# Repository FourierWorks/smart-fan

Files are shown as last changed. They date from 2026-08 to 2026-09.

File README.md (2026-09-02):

# Smart Fan Retrofit - Philips 2000 Series (CX2550/00)

Retrofitting a Philips CX2550/00 pedestal fan for control via Home Assistant,
without modifying the fan's mains wiring. An ESP32 running ESPHome electronically
"presses" the fan's existing buttons through optocouplers, and Home Assistant
provides the control dashboard over the native ESPHome API.

The fan's physical buttons remain fully functional - the retrofit is entirely
additive and reversible.

## Photos

**Interface board - front**

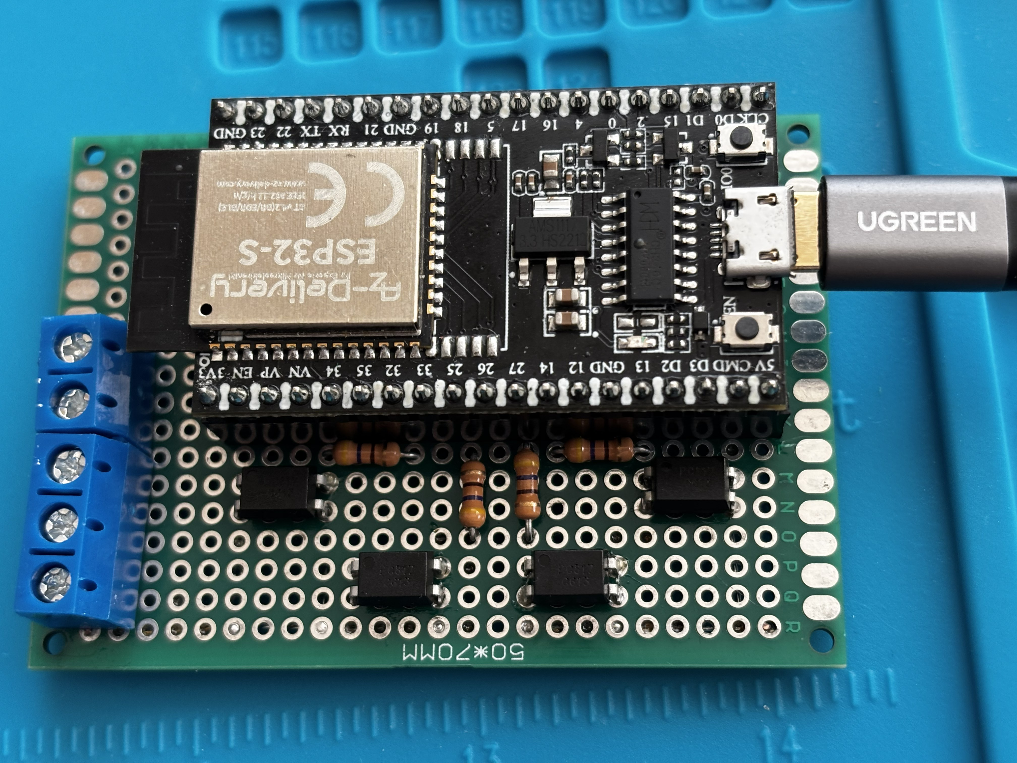
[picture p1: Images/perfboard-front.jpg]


**Interface board - back**

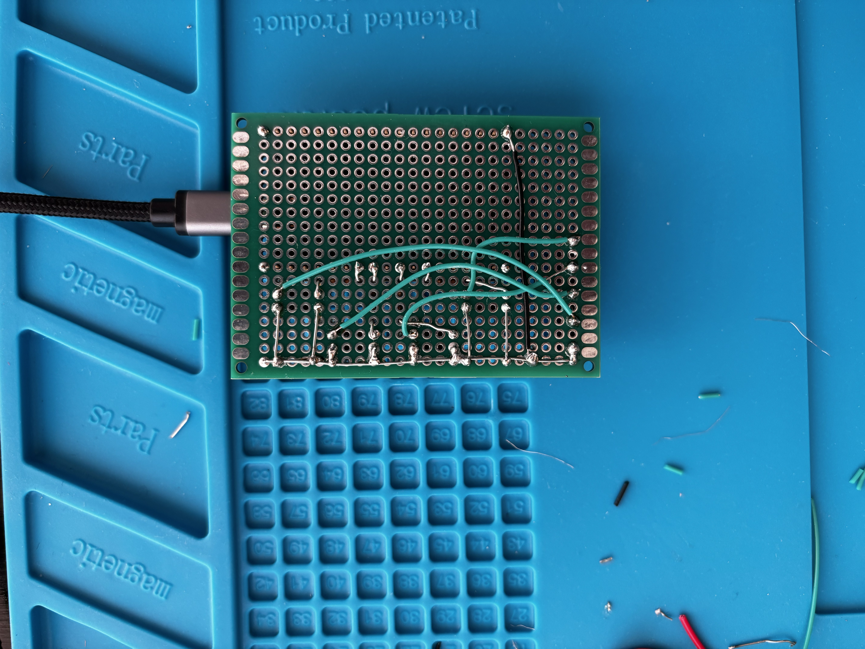
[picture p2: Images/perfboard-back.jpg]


**Installed in the fan**

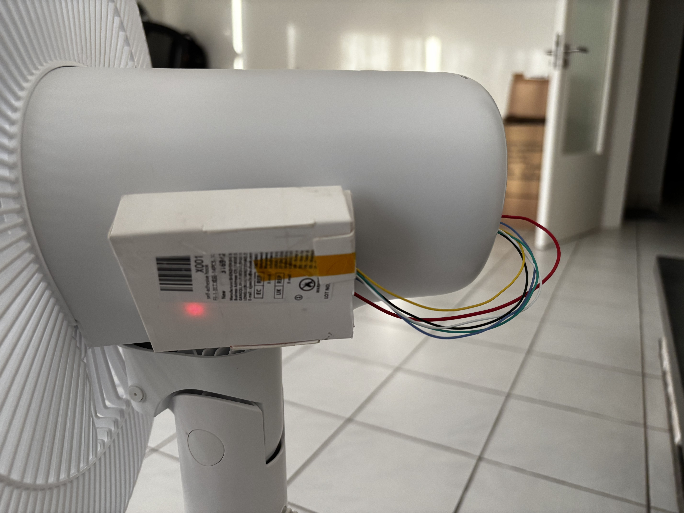
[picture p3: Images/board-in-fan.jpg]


## How it works

The fan's control board (`FS35-24CR`) is already microcontroller-driven ; its
four buttons are logic-level inputs, not mains switches. This retrofit adds an
ESP32 alongside it that:

- **Presses buttons** : a PC817 optocoupler per button, driven by an ESP32 GPIO,
  shorts the button's signal pad to ground exactly as a finger-press would.
  Wired in parallel with the physical buttons, which keep working normally.
- **Draws power** from the fan board's own onboard 5V rail (no separate supply
  needed once installed).
- **Talks to Home Assistant** over the native ESPHome API ; no custom app, no
  cloud, all on the local network.

Because there is no feedback from the fan back to the ESP32 (its indicator LEDs
turned out to be a low-voltage, multiplexed signal that wasn't practical to read),
control is **open-loop**: the ESP32 tracks the fan's state internally rather than
sensing it directly.

## Current status

Implemented and tested up to:

- **Power on/off**
- **Speed / mode select** : 5-position cycle (Speed 1, Speed 2, Speed 3, Sleep,
  Natural wind), with the ESP32 computing how many button presses are needed to
  reach the selected mode
- **Oscillation on/off** : turning oscillation off freezes the fan head at its
  current angle

Not yet implemented: sleep timer control (not currently being pursued; the
plan is to use a Home Assistant automation for this rather than the fan's
native timer button).

## Hardware

| Part | Notes |
| --- | --- |
| ESP32 | AZ-Delivery ESP32-S DevKit C V4 (classic ESP32-WROOM-32) |
| Optocouplers | 4× Sharp PC817, one per fan button |
| Power | Tapped from the fan board's onboard 5V rail |
| Interface board | Small perfboard hosting the ESP32 socket, optocouplers, and a screw terminal to the fan-board taps |

Note: the fan's buttons only respond to a single press if the
board is "awake" (its indicators recently lit). After roughly 5 secs (for sleep mode) or a minute (for all other modes/actions) of
inactivity the board goes to sleep, and the first press on any button only
wakes it ; a second press is needed to actually act. The firmware accounts for
this automatically.

## Software

Firmware is written in [ESPHome](https://esphome.io/) and controlled through
[Home Assistant](https://www.home-assistant.io/) over the native API ; no
custom app or PWA. See the project documentation for the full requirements,
architecture, and staged firmware build-up used to develop and test this.

## Known limitations

- Open-loop control: the firmware's model of the fan's state can drift if the
  physical buttons are used directly. This self-corrects on the next command
  sent from Home Assistant.
- No mains wiring is modified anywhere in this project - all ESP32 connections
  are at logic level (buttons and the low-voltage rail).

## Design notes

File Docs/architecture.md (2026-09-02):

# Architecture — Smart Fan Retrofit (Philips CX2550/00)

## 1. Design principle

The fan's board (`FS35-24CR`) is MCU-driven: buttons are logic inputs and a 5 V
rail powers its MCU. The retrofit interfaces **only at logic level** — an ESP32
running ESPHome electronically presses the four buttons via optocouplers and draws
power from the board's 5 V rail. No mains wiring is touched; the physical buttons
still work; the whole mod is reversible.

Control is **open-loop**: the ESP32 does not read the fan's LEDs. It maintains an
internal model of the fan's state and infers the board's awake/asleep condition
from its own activity timer.

## 2. System context

```mermaid
flowchart LR
    A[Phone / Browser] -->|Wi-Fi| B[Home Assistant<br/>Raspberry Pi]
    B -->|Native API / Wi-Fi| C[ESP32<br/>ESPHome]
    B --- D[UI, Automations,<br/>Scheduling]
    C -->|Logic-level<br/>button drive + 5V tap| E[Fan Board<br/>FS35-24CR]
    E -->|Unchanged| F[Motor + Oscillation]
```

- User interacts only with Home Assistant; HA ↔ ESP32 over the native ESPHome API
  (no MQTT). All local; no cloud.
- If Pi/HA is offline, the fan still works via its physical buttons.

## 3. The two physical tap points (open-loop → only two, not three)

### 3.1 Buttons (ESP32 → fan): "press" via PC817
A tactile button's MCU-side node sits at ~5 V (pull-up); pressing shorts it to
GND, read as a press. The ESP32 reproduces that short with a PC817 output
transistor, isolated from the fan board.

```mermaid
flowchart LR
    subgraph ESP["ESP32 / Input Side"]
        GPIO["ESP32 GPIO"]
        R["470 Ω"]
        A["PC817 Pin 1<br/>Anode"]
        K["PC817 Pin 2<br/>Cathode"]
        GND1["ESP32 GND"]

        GPIO --> R --> A
        K --> GND1
    end

    subgraph ISO["PC817 Optocoupler"]
        LED["Input LED"]
        T["Phototransistor"]
        A --> LED --> K
        T
        LED -. "Optical isolation" .-> T
    end

    subgraph FAN["Fan Board / Output Side"]
        PAD["Button MCU-side pad"]
        C["PC817 Pin 4<br/>Collector"]
        E["PC817 Pin 3<br/>Emitter"]
        GND2["Fan GND"]

        PAD --> C
        E --> GND2
    end

    GPIO -. "GPIO HIGH" .-> LED
    T -. "Conducts" .-> PAD
    PAD -. "Pulled to fan GND = PRESS" .-> GND2

```
- 4 channels: `SW71`, `SW72`, `SW73`, `SW74`.
- Wired in parallel with each physical button → physical buttons still work.
- Collector-high/emitter-low satisfied because the node sits above GND.

### 3.2 Power (fan → ESP32)
```
   Centre electrolytic cap (+leg) ──► ESP32 5V / VIN
   Cap stripe (−) leg  (or CN3 GND) ──► ESP32 GND
   (optional 470µF across 5V/GND for Wi-Fi spikes)
```

> Ground note: the power tap shares ground with the fan board on the ESP32 side
> (expected). The PC817s keep the button *signal* paths isolated, protecting both
> sides from wiring slips.

## 4. Complete wiring map

[View Schematic](./Perfboard_Connection.SchDoc)

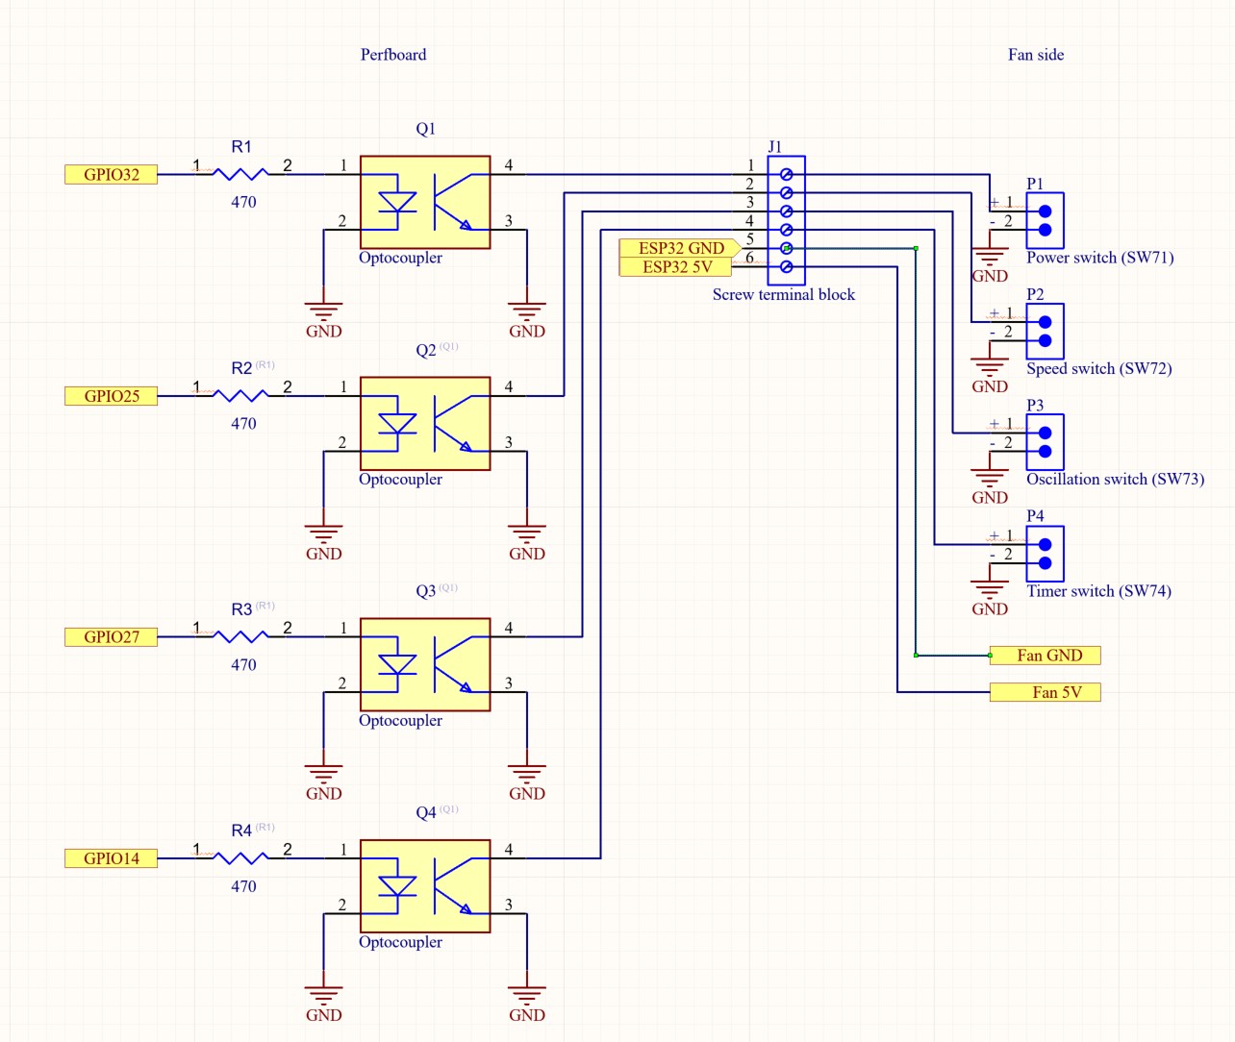
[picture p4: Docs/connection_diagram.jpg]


- 6 wires total: 4 switch button signals, 1 fan-GND (shared by emitters), 1 power.
- All land on a **screw terminal block**; ESP32 plugs into female headers.

## 5. GPIO planning (AZ-Delivery ESP32-S DevKit C V4 = classic ESP32)

Outputs only (no sensing). Avoid strapping pins for reliability.

| Function | GPIO (suggested) | Notes |
| --- | --- | --- |
| Press `SW71` (power) | GPIO32 | output |
| Press `SW72` (speed/mode) | GPIO25 | output |
| Press `SW73` (oscillation) | GPIO27 | output |
| Press `SW74` (timer) | GPIO14 | output (optional use) |

Final pins confirmed at build time; any safe output GPIO works.

## 6. ESPHome logical model (entities exposed to HA)

| Entity | Type | Backed by | Behaviour |
| --- | --- | --- | --- |
| Fan power | `switch` (or `fan`) | press `SW71` | on/off via model + awake/asleep logic |
| Fan mode | `select` (5 options) | press `SW72` ×N | targets one of speed1/2/3/sleep/natural in the 5-ring |
| Oscillation | `switch` | press `SW73` | on/off toggle; off = "stop where it is" |
| Timer | HA automation | (HA) | delayed on/off; `SW74` optional |

Each **press** is a momentary pulse: opto channel ON → hold ~pulse-width →
OFF. Implemented as ESPHome outputs/actions (design only; no code here).

## 7. Strategy C — open-loop state model + awake/asleep inference

### 7.1 State the ESP32 keeps
- `power_on` (bool) — assumed on/off
- `mode` (enum: speed1/speed2/speed3/sleep/natural)
- `oscillating` (bool)
- `t_idle` — time since the ESP32's last button press (ms)

### 7.2 Awake/asleep inference (no sensing)
- `t_idle < WAKE_THRESHOLD` (5 s if (fan mode == sleep); 60 s otherwise) → board assumed **awake** → 1 press acts.
- `t_idle ≥ WAKE_THRESHOLD` → board assumed **asleep** → first press only wakes;
  a wake press must be prepended before any acting press.
- **Every** button press resets `t_idle = 0` (any press re-lights LEDs).
- Applies to all four buttons (confirmed universal wake behaviour).

### 7.3 Boot behaviour (passive default — chosen)
- On boot the ESP32 presses **nothing**.
- It retains the model state as previous just like the fan would behave.
- The first real user command syncs intent. No spurious toggling at boot
  (e.g. after a power blip). Model may be wrong until the first command — accepted.

### 7.4 Accepted limitations
- Human use of physical buttons drifts the model until the next HA command.
- The `WAKE_THRESHOLD` inference can misfire at the boundary or under human
  interference; effect self-corrects on the next command. Recovery: re-issue the
  command, or toggle power via HA to re-establish.

## 8. Command algorithms (design; detailed in firmware plan)

All acting sequences first apply the **wake rule**: if `t_idle ≥ WAKE_THRESHOLD`,
prepend one wake press (which performs no action), then continue.

- **Power:** wake-if-needed → 1 press `SW71` → flip `power_on`.
- **Mode:** wake-if-needed → compute forward steps in ring
  `speed1→speed2→speed3→sleep→natural→speed1` from `mode` to target → that many
  `SW72` presses → set `mode`. 
- **Oscillation:** wake-if-needed → 1 press `SW73` → flip `oscillating`.
- **Timer:** handled by HA automation (delayed power command). Optional native
  path: wake-if-needed → cycle `SW74` to target.

## 9. Assembly & isolation summary
- Button signal paths optically isolated (PC817). Power path shares ground on the
  ESP32 side (expected).
- All ESP32-side parts on a small perfboard; single screw-terminal disconnect to
  the fan-board taps.
- 30 AWG taps strain-relieved with hot glue near each joint.
- ESP32 socketed on female headers; assembly secured inside the fan base, clear of
  the mains corner (`ACL/ACN/FUSE21`).

## 10. Build & bring-up order
1. Probe/confirm (done): 5 V rail, ground continuity, button GND pads.
2. Bench the ESP32 on USB: flash ESPHome, join Wi-Fi, appears in HA.
3. Build perfboard: 4× PC817 + 4× 330 Ω + socket + terminal.
4. Solder taps to `SW71`–`SW74` MCU-side pads + fan GND; strain-relieve.
5. Configure ESPHome entities + Strategy C logic (per firmware plan).
6. Verify in HA: power, 5-way mode select, oscillation, timer automation.
7. Cut ESP32 power over to the fan 5 V rail; reassemble.

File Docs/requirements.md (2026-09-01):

# Requirements - Smart Fan Retrofit (Philips CX2550/00)

## 1. Project goal

Retrofit a Philips 2000 Series pedestal fan (CX2550/00) so all functions can be
controlled from Home Assistant, without altering the fan's mains wiring and
without removing original functionality. The fan's physical buttons keep working;
the modification is fully reversible.

An added ESP32 running ESPHome electronically "presses" the fan's four existing
buttons via optocouplers. It integrates with Home Assistant (on a Raspberry Pi)
over the native ESPHome API. Home Assistant provides the UI, dashboards,
automations and scheduling ; there is no custom app/PWA.

**Control is open-loop (no feedback):** LED sensing was evaluated and dropped
(see §5). The ESP32 tracks state internally rather than reading it back.

## 2. Target hardware (the fan)  as measured

| Item | Detail |
| --- | --- |
| Fan model | Philips 2000 Series pedestal fan, CX2550/00 |
| Control board | Midea / GD `FS35-24CR` (silkscreen `FS35-24CR / FS35-24CRW-Y`) |
| Motor | `YSF-12-4-212`, GD Midea Environment Appliances (PSC induction) |
| Oscillation | Separate synchronous gearmotor, board-switched |
| Mains input | `FUSE21 3.15A/250VAC`, terminals `ACL` / `ACN` (DO NOT TOUCH) |
| Logic rail | **5 V** (confirmed: ~5 V across centre electrolytic cap; buttons idle at ~5 V) |
| 5 V source pad | **Positive leg of the centre electrolytic capacitor** near the buzzer |
| Ground | **Negative (stripe) leg of that cap**; `CN3` GND pin confirmed continuous to it |
| CN3 header (`IR/GND/5V`) | 5 V pin **dead** on this variant; GND pin usable as ground tap |
| Buttons (populated) | `SW71` ON/OFF, `SW72` SPEED/MODE, `SW73` oscillation, `SW74` TIMER |
| Indicator LEDs | Populated but **NOT used** - multiplexed, ~0.9 V lit, awkward to read |
| IR receiver | Footprint unpopulated - not used |

## 3. Confirmed control behaviour (manual + bench)

### 3.1 Power : `SW71`
- One press toggles the fan on/off **when the board is "awake"** (LEDs lit).
- See 3.5 for the awake/asleep double-press rule.

### 3.2 Speed / mode : `SW72`
Five-position cycle, **off is NOT in this cycle** (off only via `SW71`):
```
speed 1 → speed 2 → speed 3 → sleep → natural wind → (back to) speed 1
```
- Sleep mode: gradually reduces speed to lowest over ~30 min.
- Natural wind: varies speed to mimic natural breeze.

### 3.3 Oscillation : `SW73`
- Simple on/off toggle. Sweeps up to 90°.
- "Stop where it is" = toggle OFF → head freezes at current angle.

### 3.4 Timer : `SW74`
- Cycles `1h → 2h → 3h → 4h → 8h → 12h` (plus none), bidirectional
  (ends → turns fan off if on, on if off).
- **Primary timing is handled by a Home Assistant automation** (more flexible,
  bidirectional). `SW74` is wired optionally/secondary.

### 3.5 The awake/asleep LED-timeout rule (critical)
- Any state change lights the relevant indicator LED(s).
- LEDs **auto-extinguish in WAKE_THRESHOLD** seconds after the last action; the fan keeps
  running unchanged.
- **When "awake" (LEDs lit):** the first press of any button performs its action.
- **When "asleep" (idle, LEDs dark):** the first press of ANY button only
  **wakes** the board (no state change); a **second** press performs the action.
- This applies to **all four buttons** (confirmed).

## 4. Functional requirements

| # | Requirement | How met |
| --- | --- | --- |
| R1 | On/off remotely | ESP32 pulses `SW71` (with awake/asleep handling) |
| R2 | Change speed/mode | ESP32 cycles `SW72` to target in the 5-ring; exposed in HA as a 5-option `select` |
| R3 | Oscillate + stop at position | ESP32 toggles `SW73` |
| R4 | Sleep-timer config | Home Assistant automation (delayed on/off). `SW74` optional |
| R5 | Remote UI | Home Assistant app/dashboard |
| R6 | HA integration | ESPHome native API to HA on the Raspberry Pi |
| R7 | Preserve original operation | Taps in parallel with buttons; physical buttons still work |
| R8 | Reversible & safe | No mains rewiring; optically isolated button drive; removable via terminal |

## 5. Why no LED sensing (recorded decision)

The indicator LEDs read ~0.9 V to ground when lit and behave as a multiplexed,
low-side-driven matrix. This is: (a) too low to drive a PC817 input (needs >1.1 V);
(b) too low for a reliable direct 3.3 V GPIO read; (c) a scanned signal needing
time-sampling. The hardware+firmware cost of sensing is high while the benefit for
a fan is marginal (feedback only matters if someone uses the physical buttons, a
rare and self-correcting case). Decision: **open-loop control, no sensing**. Sensing the single ON LED remains a documented
future upgrade path if power-toggle reliability ever proves annoying.

## 6. Non-functional requirements

- No mains modification; ESP32 interfaces only at logic level (buttons, 5 V).
- Button drive optically isolated (PC817) between ESP32 and fan board.
- Fallback: if Pi/HA offline, fan fully usable via physical buttons.
- Serviceable: all taps land on a screw terminal block; ESP32 socketed on headers.
- Open-loop accepted limitation: physical-button use causes model drift, corrected
  on subsequent HA commands.

## 7. Bill of materials (specific, final)

### 7.1 Controller
| Qty | Part | Model | Notes |
| --- | --- | --- | --- |
| 1 | ESP32 dev board | **AZ-Delivery ESP32-S DevKit C V4** (ESP32-WROOM-32, 4 MB flash, 512 KB SRAM) | Configured in ESPHome as generic `esp32` / board `esp32dev`. USB chip: **CH340** (install CH340 driver for first flash). "S" in the name = classic ESP32, NOT S2/S3. |
| 2 | Female header strip | 2.54 mm, cut to the board's two pin rows | Socket the ESP32 (removable, no direct soldering). |

### 7.2 Button emulation (4 buttons)
| Qty | Part | Model | Purpose |
| --- | --- | --- | --- |
| 4 (buy ~10) | Optocoupler | **Sharp PC817** (bare 4-pin DIP) | One per button; output transistor across the button, isolated from ESP32. |
| 4 | Resistor | 470 Ω, 1/4 W | Sets PC817 input-LED current from 3.3 V GPIO. |

Wiring per channel: `ESP32 GPIO → 330Ω → PC817 pin1 (anode)`, `PC817 pin2
(cathode) → ESP32 GND`; `PC817 pin4 (collector) → button MCU-side pad`,
`PC817 pin3 (emitter) → fan GND`.

### 7.3 LED sensing
**None.** (See §5.)

### 7.4 Power tap
| Qty | Part | Model | Purpose |
| --- | --- | --- | --- |
| — | (fan's own 5 V) | +5 V from centre electrolytic cap positive leg; GND from its stripe leg (or CN3 GND pin) | Powers ESP32 via its 5 V/VIN input. |
| 1 (optional) | Electrolytic cap | 470 µF / 16 V | Local decoupling across 5 V/GND for Wi-Fi current spikes. |
| 1 (optional) | Buck/LDO | MP1584EN buck **or** AMS1117-3.3 | Only if the 5 V rail proves weak/noisy. |

### 7.5 Interconnect & assembly
| Qty | Part | Spec | Purpose |
| --- | --- | --- | --- |
| 1 | Perfboard | 5×7 cm | Hosts PC817s, resistors, terminal, ESP32 socket. |
| 1 | Screw terminal block | 2.54/5.08 mm | Single disconnect point for fan-board taps. |
| reel | Signal wire | **30 AWG solid-core, multi-colour** (Kynar wire-wrap) | Button + GND taps and perfboard runs. |
| short | Power wire | 24–26 AWG (red/black) | 5 V + GND power pair. |
| — | Solder / flux | 0.5–0.8 mm 63/37; no-clean flux | Fine joints. |
| — | Kapton tape  | — | Insulation + strain relief on taps. |

### 7.6 Tools
- Temp-controlled fine-tip soldering iron (~320–350 °C)
- Multimeter (continuity + DC/AC volts)
- ESPHome (standalone install on the Pi, accessed at its own IP:port) - used to
  write, compile and flash device firmware
- 5 V ≥1 A (ideally 2 A) USB supply/power bank for the testing stages

### 7.7 Existing infrastructure (actual setup)
- **Raspberry Pi 4** running **Home Assistant Container** (Docker), NOT Home
  Assistant OS. HAOS was not used because **AdGuard** already runs on the Pi and
  the Container approach coexists with it.
- **ESPHome runs standalone** (its own container/service) at its own **IP:port**,
  reachable directly - it is NOT the HAOS ESPHome add-on. It still integrates with
  Home Assistant over the device's native API.
- Consequence for device onboarding: HA may **not auto-discover** the ESP32
  (mDNS/discovery is less reliable under Container/Docker networking). If it does
  not appear automatically, add it manually: HA → Settings → Devices & Services →
  Add Integration → ESPHome → host = ESP32 IP, port = **6053**, then paste the
  device's API **encryption key**.
- Recommended: set a **DHCP reservation** for the ESP32 so its IP is stable
  (referenced by IP for manual add and for reliability).
- 2.4 GHz Wi-Fi (ESP32 is 2.4 GHz only)

## 8. Power plan by stage
- **Testing (all stages):** power the ESP32 from a **USB 5 V supply** (independent
  of the fan) while probing/pressing against the fan (fan on mains as normal,
  soldering done with fan unplugged).
- **Final install:** power the ESP32 from the **fan's 5 V rail** (centre cap),
  optionally with the 470 µF local cap.

## 9. Bench values captured (for reference)
- Logic rail: **~5 V** (centre electrolytic cap; buttons idle ~5 V).
- CN3 `5V` pin: **dead**; CN3 `GND` pin: **continuous with board ground** (usable).
- LED driven leg, lit, to ground: **~0.9 V**, multiplexed → sensing dropped.

## 10. Out of scope
- Any mains/motor-tap/triac modification.
- Arbitrary-angle oscillation positioning (only on/off "stop where it is").
- Custom PWA/web UI (superseded by Home Assistant).
- MQTT (native ESPHome API used).
- LED state sensing (documented future upgrade only).

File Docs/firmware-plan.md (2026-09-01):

# Firmware Plan - Smart Fan Retrofit (Philips CX2550/00)

*Algorithm and staging only - no code. Each stage produces an independently
verifiable result before the next begins. Built on ESPHome, integrated with Home
Assistant over the native API.*

## Conventions used in this document

- **Press** = energise a button's PC817 for a fixed pulse, then release.
  Parameters: `PULSE_MS` (how long the opto is on) and `GAP_MS` (pause between
  consecutive presses). Tuned in Stage 2.
- **`t_idle`** = time since the ESP32's last press (any button).
- **`WAKE_THRESHOLD`** = 5 s if (fan mode == sleep); 60 s otherwise (LED timeout).
- **Awake** = `t_idle < WAKE_THRESHOLD` (LEDs assumed lit → 1 press acts).
- **Asleep** = `t_idle ≥ WAKE_THRESHOLD` (first press only wakes; no action).
- **Model** = the ESP32's assumed fan state: `power_on`, `mode`, `oscillating`.
- **Mode ring** (SW72, forward only): `speed1 → speed2 → speed3 → sleep →
  natural → speed1`. Off is NOT in the ring (off only via SW71).

---

## Stage 0 : Environment & safety baseline

**Goal:** tooling ready; no fan interaction yet.

**Steps:**
1. Install ESPHome (standalone or the Home Assistant add-on).
2. Install the CH340 USB driver for the AZ-Delivery board.
3. Confirm Home Assistant is reachable and the ESPHome dashboard opens.
4. Power rule for all later stages: ESP32 on **USB 5 V** during testing; the fan
   is only mains-powered when observing a press; soldering is done fan-unplugged.

**Independent test / exit criterion:**
- ESPHome dashboard loads; the board's serial port appears when plugged in.

---

## Stage 1 : Bare board bring-up (network only)

**Goal:** ESP32 runs ESPHome, joins Wi-Fi, appears in Home Assistant. No fan
wiring involved.

**Steps:**
1. Create a minimal ESPHome device config: board = generic `esp32`/`esp32dev`,
   Wi-Fi credentials, native API key, OTA enabled.
2. Flash once over USB.
3. Confirm the device connects to Wi-Fi and is discovered by Home Assistant; add
   it.
4. Add one trivial diagnostic entity (e.g. an on-board status indicator or uptime
   sensor) purely to confirm the API link.

**Independent test / exit criterion:**
- Device shows **online** in Home Assistant.
- The diagnostic entity updates in HA.
- A subsequent config change flashes successfully **over-the-air** (no USB).

---

## Stage 2 : One button, one pulse (single-channel actuation)

**Goal:** prove the ESP32 → PC817 → fan-button chain physically presses **one**
button, and tune the pulse timing. Use the **power button (SW71)** as the test
channel.

**Prerequisite hardware:** PC817 #1 wired for SW71 (GPIO→330Ω→opto→button node/
fan GND); ESP32 on USB; fan on mains.

**Steps:**
1. Expose a single manual "Press SW71" action/button entity in HA that fires one
   press with parameters `PULSE_MS`, `GAP_MS`.
2. Fire it once with a starting `PULSE_MS` (e.g. a value in the tens-of-ms range)
   while the fan is **awake** (press a physical button first so LEDs are lit).
3. Observe: exactly one power toggle should occur.
4. Tune `PULSE_MS` up/down until presses are 100% reliable (too short = missed;
   too long = risk of double-register). Record the working `PULSE_MS`.
5. Fire two presses back-to-back to tune `GAP_MS` so they register as two distinct
   presses (fan toggles off then on). Record `GAP_MS`.

**Independent test / exit criterion:**
- One fired press → exactly one power toggle, repeatable 10/10 times.
- Two fired presses → two toggles (ends where it started), repeatable.
- `PULSE_MS` and `GAP_MS` values recorded for reuse.

*Note: at this stage ignore awake/asleep ; always pre-wake manually. The
awake/asleep logic is added in Stage 4.*

---

## Stage 3 : All four buttons as raw momentary actions

**Goal:** each of the four buttons can be individually actuated from HA. 

**Prerequisite hardware:** all 4 PC817s wired (SW71–SW74).

**Steps:**
1. Wire and expose four manual press actions in HA: Press SW71, SW72, SW73, SW74,
   each using the tuned `PULSE_MS`/`GAP_MS`.
2. With the fan **awake**, fire each button once and confirm the expected physical
   effect:
   - SW71 → power toggles.
   - SW72 → mode advances one step in the ring.
   - SW73 → oscillation toggles.
   - SW74 → timer advances one step.
3. Verify no cross-talk: firing one channel never actuates another (checks wiring/
   isolation).

**Independent test / exit criterion:**
- Each of the four actions produces only its own button's effect, repeatable.
- No channel triggers a neighbour.

---

## Stage 4 : State model + awake/asleep wake logic

**Goal:** introduce the internal model and the `t_idle`- based wake handling, so a
single logical "do X" reliably performs X whether the board is awake or asleep.
This is the heart of open-loop control.

**Steps (algorithm):**
1. Add model variables: `power_on`, `mode`, `oscillating`, and a running
   `t_idle` timer that resets to 0 on every press.
2. Define a **`press(button)`** primitive that fires one pulse and resets
   `t_idle = 0`.
3. Define a **`wake_if_needed()`** routine:
   ```
   if t_idle >= WAKE_THRESHOLD:
       press(button_to_wake)   # performs no action when asleep
   ```
   **Wake-button choice** : Same button as action
4. Define an **`act(button, n=1)`** wrapper:
   ```
   wake_if_needed()
   repeat n times: press(button)  (respecting GAP_MS)
   ```
5. Boot behaviour : on boot press nothing; Retain the previous states.

**Independent test / exit criterion:**
- With the board **awake**, `act(SW71)` toggles power once.
- Let the board go **asleep**, then `act(SW71)`: the fan still
  toggles exactly once (the wake press + the action are handled correctly). Test for both wake times (5 s and 60 s)
- Repeat the asleep test several times → reliable single logical action each time.

---

## Stage 5 : Power on/off control (user-facing)

**Goal:** a Home Assistant on/off control that maps to the model + wake logic.

**Steps (algorithm):**
1. Expose a `switch` (or `fan` on/off) entity.
2. On "turn on": if `power_on` is false → `act(SW71)`; set `power_on=true`.
   On "turn off": if `power_on` is true → `act(SW71)`; set `power_on=false`.
   (If model already matches the request, do nothing - avoids redundant toggles.)

**Independent test / exit criterion:**
- From a known off state, HA "on" starts the fan; HA "off" stops it; repeatable
  both when awake and after the asleep timeout.
- Rapid on→off→on sequences behave correctly (chained commands stay awake, so only
  the first pays the wake cost).

---

## Stage 6 : Speed/mode select (5-position ring)

**Goal:** a 5-option selector in HA that lands on the requested mode via computed
SW72 presses.

**Steps (algorithm):**
1. Expose a `select` with options: `speed1, speed2, speed3, sleep, natural`.
2. On selection of `target`:
   ```
   if not power_on:
    turn_on()          # presses SW71 once; fan resumes its last mode on its own
    power_on = true
    # mode is left untouched here, the hardware already remembers it

   steps = forward_distance(mode -> target) in the ring
   act(SW72, n=steps)
   mode = target
   ```
   - `forward_distance` counts steps going forward only around
     `speed1→speed2→speed3→sleep→natural→speed1` (e.g. speed3→speed1 = 2 steps:
     natural, speed1).

**Independent test / exit criterion:**
- Turn the fan on from off, off again, then back on repeatedly at different modes, confirming each time that the fan resumes the same mode it was on before it was switched off.
- From each of the five modes, selecting each of the five targets lands correctly (5x5 matrix spot checked), awake and asleep.
---

## Stage 7 : Oscillation toggle ("stop where it is")

**Goal:** an on/off control for oscillation.

**Steps (algorithm):**
1. Expose an oscillation `switch`.
2. On "on": if `oscillating` is false → `act(SW73)`; set `oscillating=true`.
   On "off": if `oscillating` is true → `act(SW73)`; set `oscillating=false`.

**Independent test / exit criterion:**
- HA "oscillation on" starts the sweep; "off" stops it and the head **freezes at
  its current angle** (the core requirement), awake and asleep.
- Model stays consistent across several toggles.

---

## Stage 8 : Sleep timer (Home Assistant automation - primary path)

**Goal:** configurable sleep timer, implemented in Home Assistant rather than the
fan's native timer.

**Steps (algorithm, in HA):**
1. Expose a `number` or `select` in HA for the desired duration (e.g. minutes/
   hours), plus a "start sleep timer" control.
2. HA automation: on start, wait the chosen duration, then call the ESP32 power
   `turn_off` (Stage 5). Optionally support delayed-on (if fan is off, turn on
   after the duration) to mirror the fan's bidirectional native behaviour.
3. Provide a "cancel timer" control that clears the pending automation.

**Optional native path (secondary):** if native timer is ever wanted, implement
`act(SW74, n=steps)` targeting the timer ring `1h→2h→3h→4h→8h→12h→none`, mirroring
Stage 6's ring logic. Not required for the primary design.

**Independent test / exit criterion:**
- Setting a short test duration (e.g. 1–2 min) turns the fan off at the right time.
- Cancel prevents the shutoff.
- (If native path implemented) SW74 lands on the requested hour.

---

## Stage 9 : Consolidation, guard rails, dashboard, install

**Goal:** harden the logic and finish the user experience, then move to the final
install.

**Steps:**
1. **Guard rails:** cap every press loop at the ring length so a bad count can
   never spin indefinitely; add minimum spacing between logical commands so bursts
   don't overrun the fan's own debounce.
2. **Chained-command correctness:** verify that issuing several commands in quick
   succession only pays the wake cost once (first command) and all land correctly.
3. **Threshold tuning:** re-check `WAKE_THRESHOLD` against the fan's real timeout.
4. **Dashboard:** arrange power, mode select, oscillation, and sleep-timer controls
   in Home Assistant.
5. **Resync affordance:** add an HA "resync/known-state" button that drives the fan
   to a defined state and resets the model (useful after someone used the physical
   buttons).
6. **Install:** cut ESP32 power from USB to the fan's 5 V rail; secure the perfboard
   and ESP32 inside the base; strain-relieve; reassemble.

**Independent test / exit criterion (end-to-end):**
- Full run: power on → each of 5 modes → oscillation on/off → sleep timer → power
  off, all from Home Assistant, awake and after asleep timeouts.
- After a deliberate physical-button change, the resync control restores a known,
  correct state.
- Fan runs on its own 5 V rail (USB removed) with everything still functional.

---

## Testing philosophy (why staged)

Each stage adds exactly one new capability on top of a verified base:
network (1) → one press (2) → four presses (3) → wake logic + model (4) →
power (5) → mode (6) → oscillation (7) → timer (8) → hardening/install (9).
If a stage's exit test fails, the fault is isolated to that stage's addition ; no
whole-firmware debugging. Stages 2 and 4 are the highest-value checkpoints:
Stage 2 proves the physical actuation and timing; Stage 4 proves the open-loop
awake/asleep model that everything above depends on.

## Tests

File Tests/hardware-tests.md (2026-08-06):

# Hardware Tests — Smart Fan Retrofit (Philips CX2550/00)

Running log of bench and integration tests. Each entry records what was tested,
the setup, the expected result, the actual result, and pass/fail. Newest stages
are appended as they are completed.

---

## Environment / setup reference

- **ESP32:** AZ-Delivery ESP32-S DevKit C V4 (classic ESP32-WROOM-32). USB: CH340.
- **ESPHome board definition:** Generic ESP32 Board (`esp32dev`), arduino framework.
- **Home Assistant:** HA **Container** on Raspberry Pi 4 (alongside AdGuard).
- **ESPHome:** standalone install on the Pi, own IP:port (not a HAOS add-on).
- **Opto test resistor to GPIO:** 220 Ω or 470 Ω acceptable (either used for bench).
- **Fake button node (bench):** 5 V → 10 kΩ pull-up → node → PC817 pin 4;
  PC817 pin 3 → GND. Node read with multimeter and/or LED+~1 kΩ indicator.

---

## Test 1 — ESP32 GPIO → PC817 drive (bench, no Home Assistant)

**Goal:** confirm the ESP32 can drive a PC817 optocoupler and that the opto output
pulls a pulled-up "fake button" node from ~5 V down to ~ground — i.e. the button-
press topology works, with correct polarity.

**Setup:**
- Firmware: standalone Arduino sketch toggling one GPIO (GPIO25) HIGH/LOW on a
  timer (no ESPHome, no HA).
- Input side: GPIO25 → 220/470 Ω → PC817 pin 1 (anode); PC817 pin 2 → ESP32 GND.
- Output side: 5 V → 10 kΩ → fake node → PC817 pin 4 (collector); PC817 pin 3
  (emitter) → GND.
- Indicator: LED (anode → 5 V) in series with ~1 kΩ to the fake node, to visualise
  the node being pulled low. Multimeter also on the node.

**Expected:**
- GPIO LOW (opto off) → node ~5 V, indicator LED off.
- GPIO HIGH (opto on) → node ~0.1–0.3 V, indicator LED on.

**Actual:** Indicator LED blinks in step with the GPIO toggle — node is being
pulled low when the opto is driven and released when it isn't. Behaviour matches
the button-press topology.

**Result:** ✅ **PASS** — ESP32→PC817→node drive verified; polarity correct.

**Notes:**
- This exercises switching behaviour. True galvanic isolation is not exercised on
  the bench because the output side shares the ESP32's 5 V/GND; it will be isolated
  in the real build (ESP32 GND vs fan GND).
- Pulse-width (`PULSE_MS`) / gap (`GAP_MS`) tuning deliberately deferred to Stage 2
  against the real fan, where the fan MCU is the arbiter of a registered press.

---

## Test 2 — Stage 1 ESPHome bring-up + Home Assistant control

**Goal:** ESP32 runs ESPHome, joins Wi-Fi, connects to Home Assistant over the
native API, and HA can both read data from and send commands to the device.

**Setup:**
- Firmware: Stage 1 ESPHome config (Wi-Fi, native API, OTA, diagnostics:
  Uptime, WiFi Signal, IP Address; plus a GPIO switch on GPIO25 — "ON/OFF").
- First flash: **Factory image** downloaded from standalone ESPHome (compiled on
  the Pi) and flashed to the ESP32 via **web.esphome.io** over USB from the laptop.
- Device added to HA (Container) via the ESPHome integration (host = ESP32 IP,
  port 6053, API encryption key).

**Expected:**
- Device shows online in ESPHome logs; Wi-Fi connects; API starts.
- In HA: device online; Uptime climbs; IP/WiFi entities populate (ESP32 → HA).
- Toggling the GPIO switch from HA drives the hardware pin (HA → ESP32).

**Actual:** Device flashed and came online. From Home Assistant, an LED connected
to the GPIO pin can be switched **on and off**, confirming HA → ESP32 command flow.

**Result:** ✅ **PASS** — HA ↔ ESP32 link verified in both directions;
HA → ESP32 command control (the critical direction for button presses) confirmed.

**Notes:**
- HA is Container-based, so device onboarding may require the **manual** ESPHome
  integration add (IP + 6053 + key) rather than auto-discovery.
- After this first USB flash, subsequent firmware updates use **OTA** (wireless).
- Corresponds to **Stage 1** exit criteria in firmware-plan.md.

---

## Test 3 — OTA flash + second opto channel + 4-speed (blink) select + dashboard

**Goal:** extend the Stage 1 bench setup to prove three additional capabilities
before moving to the real fan: (a) **wireless OTA flashing** (no USB), (b) a
**second independent opto channel** on GPIO26, and (c) a **select entity that
cycles a control through multiple states** — the structural preview of the real
Stage 6 speed/mode selector. "Speed" here = LED **blink rate** (the PC817 switches
on/off, so speed is expressed as blink frequency, not brightness).

**Setup:**
- Firmware: Stage 1 config extended with — a global `blink_period_ms`; a GPIO
  switch `opto2` on **GPIO26** driving a second PC817; an `interval` (50 ms tick)
  that toggles `opto2` at the current blink period; a template `select`
  "Speed" with options Off / Low / Medium / High mapping to blink
  periods 0 / 1000 / 400 / 150 ms.
- Wiring: GPIO26 → 470 Ω → PC817#2 pin1; pin2 → GND; output side 5 V → LED →
  ~1 kΩ → PC817#2 pin4 (collector); pin3 (emitter) → GND (LED as visible load).
- **Flashed via OTA (wireless)** from standalone ESPHome on the Pi — no USB.
- Dashboard: HA cards arranged **UI-only** (no YAML dashboard edits) — an ON/OFF
  control and the 4-option Speed selector; entity names set in ESPHome YAML.

**Expected:**
- OTA flash completes wirelessly; device reboots and reconnects; no cable.
- New entities appear in HA automatically.
- Speed select: Off → LED dark; Low → slow blink; Medium → faster; High → fastest.
- Existing "ON/OFF" (GPIO25) still toggles (no regression).

**Actual:** OTA flash succeeded wirelessly (first flash after the initial USB one).
New entities appeared in HA. The 4-option selector changes the LED blink rate as
expected across Off/Low/Medium/High, driving the PC817 on GPIO26. Dashboard cards
were customised purely from the HA UI.

**Result:** ✅ **PASS** — OTA workflow confirmed (all future flashes wireless);
second opto channel verified; select-drives-control pattern (preview of Stage 6)
working end-to-end from HA through the ESP32 to a real PC817.

**Notes:**
- Confirms the full control chain on the bench: HA select → ESPHome logic
  (globals + interval + lambda) → GPIO → PC817 switching. Structurally identical
  to the real button control, minus the fan.
- Dashboard appearance is stored on the HA side (independent of firmware); future
  logic re-flashes do **not** affect it, provided entity names are unchanged.
- Still USB-powered ESP32; still bench; not connected to the fan.

---

## Pending / upcoming tests

**Test target from Stage 2 onward = the REAL fan, not a mimic.** The bench
fake-button-node (LED) rig in Test 1 was a one-time opto-validation only; it cannot
verify press registration, the speed/mode cycle, oscillation, or the awake/asleep
LED-timeout behaviour — those only exist on the real board. So Stages 2–8 are run
with the PC817 outputs connected to the **actual fan button pads**, while:
- the **ESP32 stays USB-powered** (independent of the fan) through Stage 8,
- the fan runs on mains as normal,
- the perfboard/ESP32 remain **loose on the bench** (not yet installed in the base),
- soldering is done with the fan **unplugged**; power only applied to observe.

**Stage 9 is not the first real-fan test** — it is the transition from this bench
configuration to **permanent install**: move ESP32 power from USB to the fan's 5 V
rail, secure and strain-relieve everything inside the base, and re-run the full
end-to-end test to confirm reassembly didn't disturb anything.

Tracked against firmware-plan.md stages (to be logged as completed):

- **Stage 2** — single button (SW71) against the real fan; tune `PULSE_MS`/`GAP_MS`;
  confirm one fired press = exactly one power toggle (awake).
- **Stage 3** — all four buttons individually actuate; no cross-talk.
- **Stage 4** — state model + awake/asleep (`t_idle`) wake logic; single logical
  action reliable when awake and after the ~1 min asleep timeout.
- **Stage 5** — HA power on/off via the model.
- **Stage 6** — 5-mode select via SW72 ring; confirm power-on default (anchor).
- **Stage 7** — oscillation on/off ("stop where it is").
- **Stage 8** — sleep timer via HA automation.
- **Stage 9** — guard rails, dashboard, resync control, final install on fan 5 V.

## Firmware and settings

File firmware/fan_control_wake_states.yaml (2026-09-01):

esphome:
  name: fan
  friendly_name: fan

  on_boot:
    priority: -100
    then:
      - lambda: |-
          id(fan_power_state_fb).publish_state(false);
          id(fan_mode_state_fb).publish_state("Unknown");
          id(oscillation_state_fb).publish_state("Stopped");

################################################
captive_portal:

# ---- Stage 1 diagnostics: prove the API link is alive ----

# Uptime: a value that visibly increments in HA
sensor:
  - platform: uptime
    name: "Uptime"

  - platform: wifi_signal
    name: "WiFi Signal"
    update_interval: 60s

text_sensor:
  - platform: wifi_info
    ip_address:
      name: "IP Address"
  # STATE INDICATORS (Dashboard)
  - platform: template
    name: "Speed State"
    id: fan_mode_state_fb
  - platform: template
    name: "Oscillation State"
    id: oscillation_state_fb


# ================= GLOBALS =================
globals:
  - id: power_on
    type: bool
    restore_value: no
    initial_value: 'false'
  - id: fan_mode              # 0 = unknown, 1..5 = Speed1,Speed2,Speed3,Sleep,Natural
    type: int
    restore_value: no
    initial_value: '0'
  - id: oscillating
    type: bool
    restore_value: no
    initial_value: 'false'
  - id: last_press_ms
    type: uint32_t
    restore_value: no
    initial_value: '0'
  - id: never_pressed
    type: bool
    restore_value: no
    initial_value: 'true'
  - id: anchor_mode           # fallback ONLY when fan_mode is still unknown (fresh boot)
    type: int
    restore_value: no
    initial_value: '1'
  - id: pending_wake
    type: bool
    restore_value: no
    initial_value: 'false'
  - id: target_mode
    type: int
    restore_value: no
    initial_value: '1'

# ================= OUTPUTS =================
output:
  - platform: gpio
    pin: GPIO32
    id: sw71_out        # power
  - platform: gpio
    pin: GPIO25
    id: sw72_out        # speed / mode
  - platform: gpio
    pin: GPIO27
    id: sw73_out        # oscillation
  - platform: gpio
    pin: GPIO14
    id: sw74_out        # timer

# ================= TUNABLES =================
number:
  - platform: template
    name: "Press Pulse ms"
    id: press_pulse_ms
    optimistic: true
    min_value: 40
    max_value: 500
    step: 10
    initial_value: 120
    mode: box
  - platform: template
    name: "Press Gap ms"
    id: press_gap_ms
    optimistic: true
    min_value: 50
    max_value: 1000
    step: 25
    initial_value: 250
    mode: box
  - platform: template
    name: "Wake Threshold s"
    id: wake_threshold_s
    optimistic: true
    min_value: 10
    max_value: 120
    step: 5
    initial_value: 60
    mode: box
  - platform: template
    name: "Wake Threshold Sleep Mode s"
    id: wake_threshold_sleep_s
    optimistic: true
    min_value: 2
    max_value: 30
    step: 1
    initial_value: 5
    mode: box
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

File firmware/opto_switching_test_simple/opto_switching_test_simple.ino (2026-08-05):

#define OPTO_PIN 25

void setup() {
  // put your setup code here, to run once:
  Serial.begin(115200);
  delay(1000);
  pinMode(OPTO_PIN, OUTPUT);

}

int state = LOW;

void loop() {
  // put your main code here, to run repeatedly:
  state = !state;
  digitalWrite(OPTO_PIN, state);
  Serial.println(state ? "OPTO ON  - node should be ~0.2V" : "OPTO OFF - node should be ~5V");
  delay(10000);
}

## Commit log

2026-08-06 Test3 of stage1 execution update
2026-09-01 Wake threshold fix for sleep mode
    [fan_control_wake_states.yaml]
2026-09-02 Schematic diagram added
    [Perfboard_Connection.SchDoc]
2026-09-02 Schematic diagram updated in architecture.md
